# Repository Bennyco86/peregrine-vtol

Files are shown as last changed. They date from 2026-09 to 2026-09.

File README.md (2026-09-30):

# Peregrine: open-source VTOL FPV tail-sitter

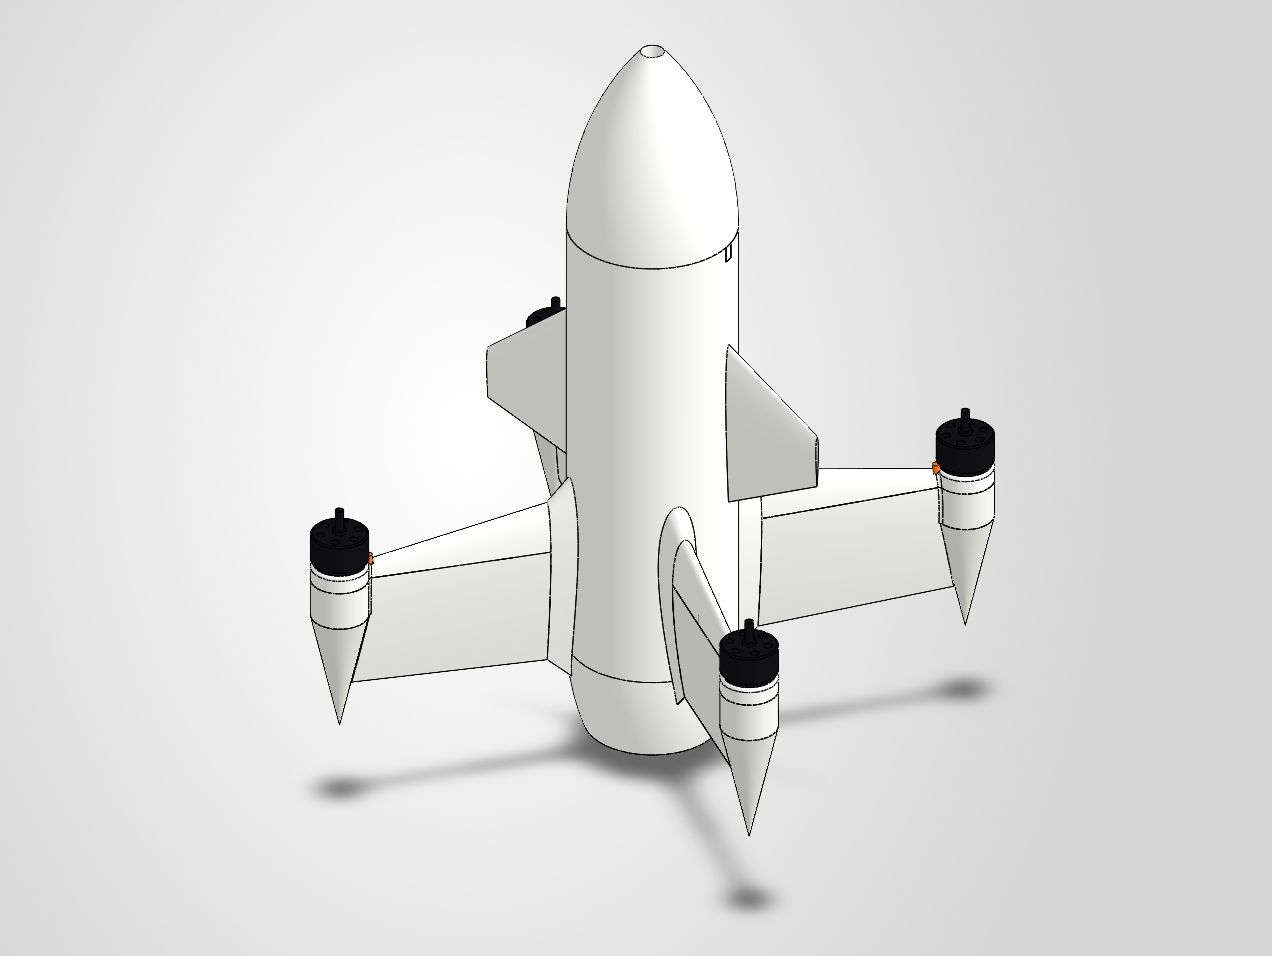
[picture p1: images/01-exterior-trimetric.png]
Peregrine, exterior


**Peregrine** (named after the peregrine falcon, the fastest animal on Earth) is a hobby **VTOL tail-sitter**. It stands on its four wing-tip spikes, takes off and hovers like a quadcopter, then pitches nose-forward and flies on its wings. It uses four motors and no control surfaces. **Design target: 200 km/h (56 m/s) in forward flight.**

I used **Claude Opus 5.5** and CAD to design it from a photo of the new Ukrainian interceptor drone, then gave it my own twist: it is built around **hobbyist components that are easy to find**. It is shared as an **open-source FPV project**.

> Fly it within your local aviation rules.

## What's in the repo

| Folder / file | Contents |
|---|---|
| [`cad/step/`](cad/step) | STEP files of every part designed here, plus the full assembly without vendor parts. **Print the `Rev 2` body parts.** The assembly STEP and the renders still show the original one-piece body. |
| [`BOM.md`](BOM.md) | Full bill of materials with purchase links, radio and goggle recommendations |
| [`docs/WIRING.md`](docs/WIRING.md) | Every cable, connector, pad and route |
| [`software/SETUP.md`](software/SETUP.md) | Flashing ArduPilot, calibration, radio, OSD, first flights |
| [`software/ardupilot/`](software/ardupilot) | ArduPlane parameter file for the Kakute H7 (QuadPlane tail-sitter, airspeed sensor, high-speed gain scaling) |
| [`images/`](images) | CAD renders (exterior, x-ray, wiring) and CFD (airflow simulation) results |

## Key numbers

| | |
|---|---|
| Layout | Quad tail-sitter, motors at 45° / 135° / 225° / 315°, 190 mm from the axis |
| Length | about 460 mm (tail to nose) |
| Body | Ø100 mm tube, ogive nose, 2 swept canards, 4 aerofoil wings (NACA 00xx) |
| Power | 4 × 2807 1300 KV, 7″ tri-blade high-pitch props (7×5 / 7×6), 6S 2200 mAh |
| Top speed target | 200 km/h (56 m/s), with an airspeed sensor and speed-based gain scaling |
| Structure | 3D-printed in ASA or PA-CF |
| Flight controller | Holybro Kakute H7 + Tekko32 F4 50A 4-in-1 |
| Firmware | ArduPilot **ArduPlane** (`Q_TAILSIT_ENABLE = 2`, copter-motor tail-sitter) |
| Video | HDZero Freestyle V2 + Micro V3 camera (digital, MSP OSD) |
| RC | ExpressLRS 2.4 GHz |
| GPS | Holybro Micro M10 in the nose |

## Build notes

- **Split wings.** Each wing is a top part (leading-edge beam + motor nacelle) and a bottom part (panel), split along the seam line. The motor leads lie in a groove on the split face before the halves are pinned and glued, so nothing has to be threaded through a closed wing.
- **Tabbed root.** The wings slide into slots in the body's aerofoil root fairings.
- **Three-piece fuselage (Rev 2), so it prints on 250 mm printers.** `Tail Cap Rev 2` (42 mm) + `Body Rev 2` (245 mm) + `Nose Cone Rev 2` (159 mm) + `Nose Tip Rev 2` (64 mm). The joints are flush twist-lock bayonets (3 lugs, about 18° twist, snap bump) set inside the wall thickness, so the bore stays clear for the tray. The tail cap is glued; the nose is left unglued as a service hatch, and a wide key lug means it only fits one way. Test-print one joint first: the fit is designed with 0.2 mm clearance.
- **Screw-off nose tip for the camera.** `Nose Tip Rev 2` screws onto a threaded collar on the nose bulkhead (2.5 mm pitch, printable without supports when printed tip-up). Unscrew it to drop the camera into its cradle, fit the two M2 pivot screws from the side, and reach the GPS screws through the bulkhead. The collar sits entirely inside the tip, so the outer shape is unchanged.
- **Optional stiffener channels.** The wing panels (Ø6.2 mm) and canards (Ø2.1 mm) have empty channels in the CAD. They are not required and nothing for them is in the BOM; fill them with carbon tube/rod only if a printed part turns out too flexible.
- **Wiring.** All wiring is modelled and colour-coded in the CAD: orange = motors, red = battery, yellow = VTX power/UART, black = video coax, blue = MIPI, cyan = GPS, green = receiver.

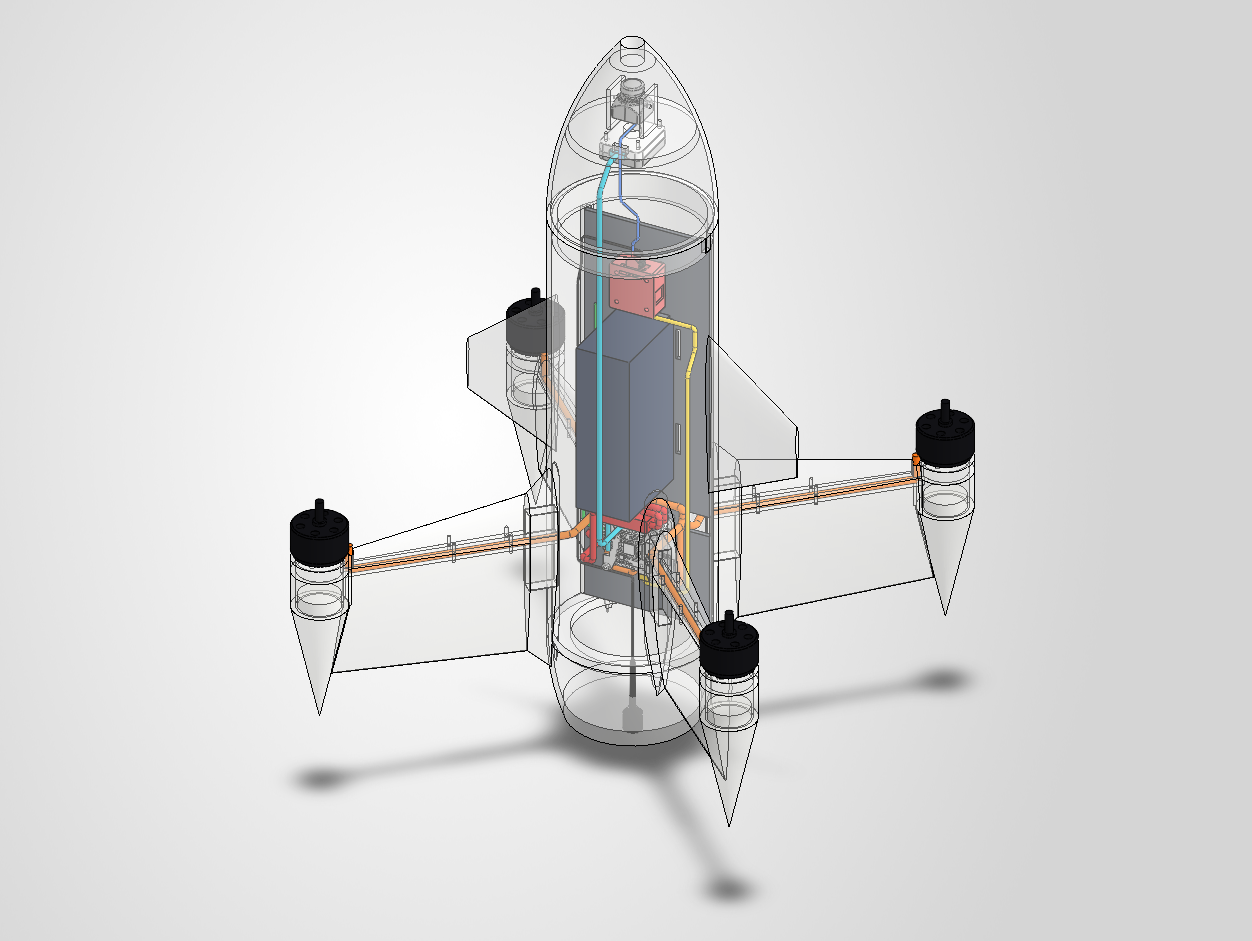
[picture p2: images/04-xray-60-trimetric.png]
x-ray

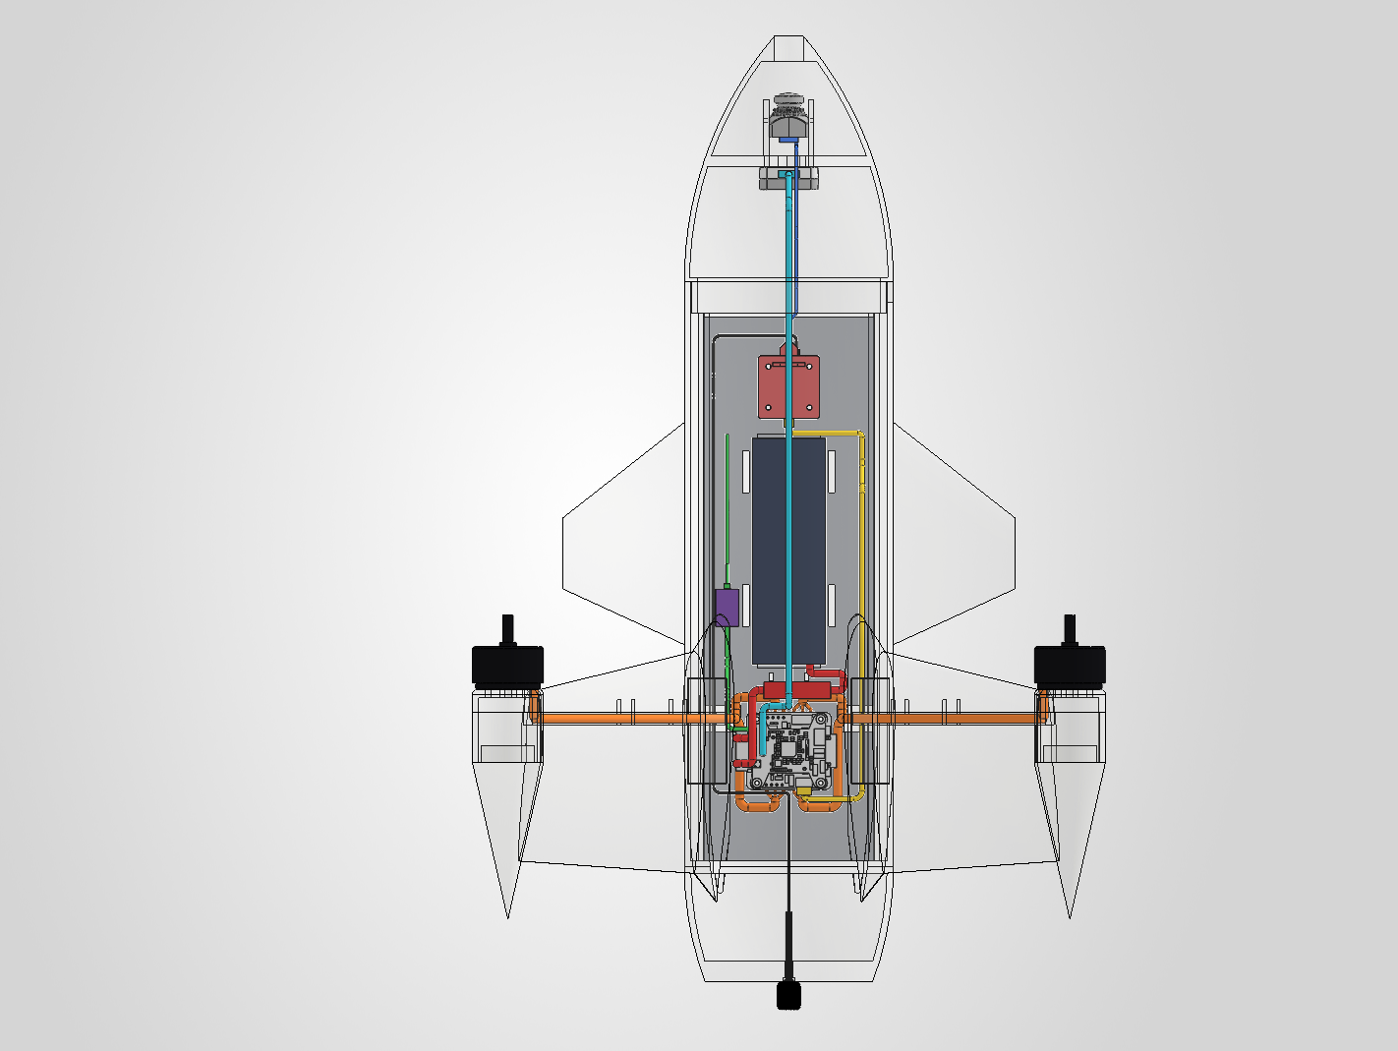
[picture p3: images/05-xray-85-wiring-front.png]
wiring, 85% transparent


| Front | Top (hover attitude) |
|---|---|
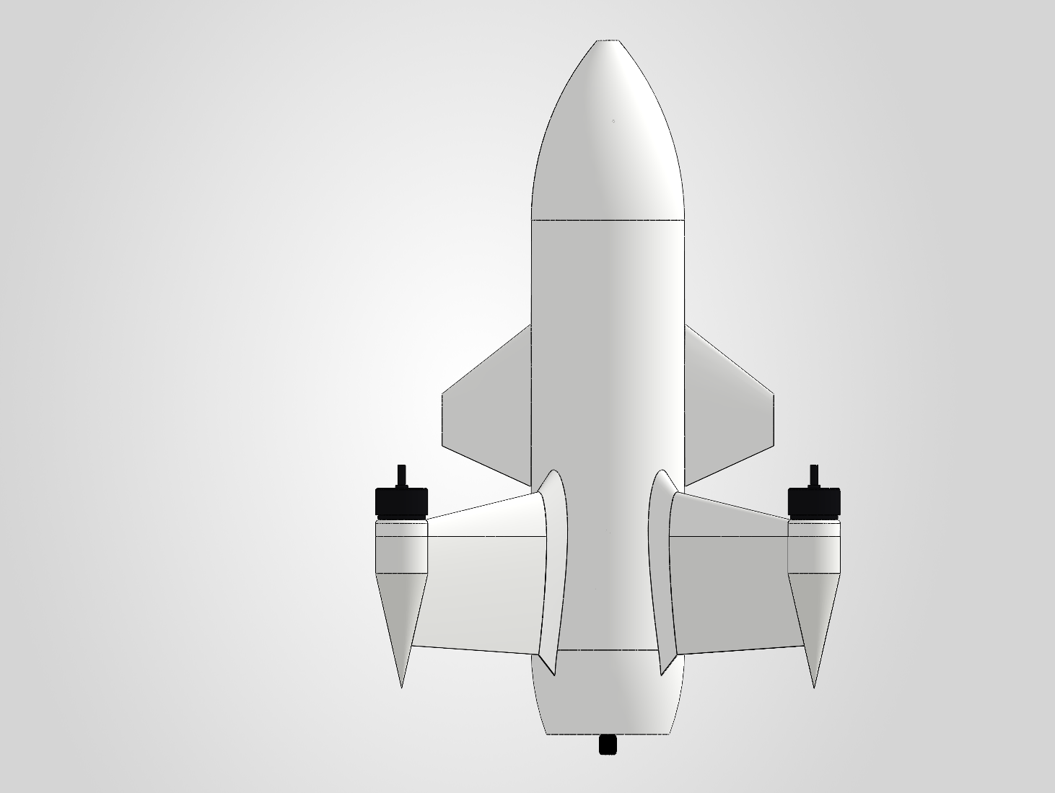
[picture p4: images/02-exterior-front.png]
front
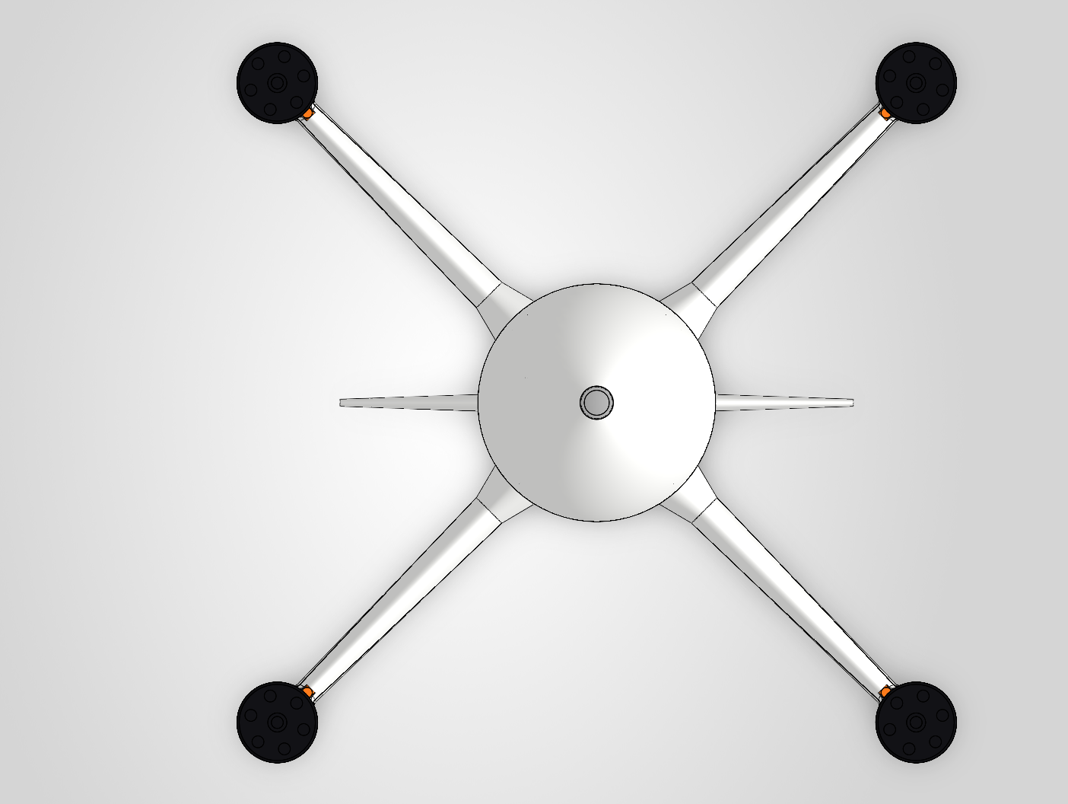
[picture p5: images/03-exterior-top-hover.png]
top
|  |  |

## CFD (airflow simulation)

External-flow CFD on the outer shape only (internal parts removed), air, nose-first forward flight.

### At the 200 km/h target (56 m/s)

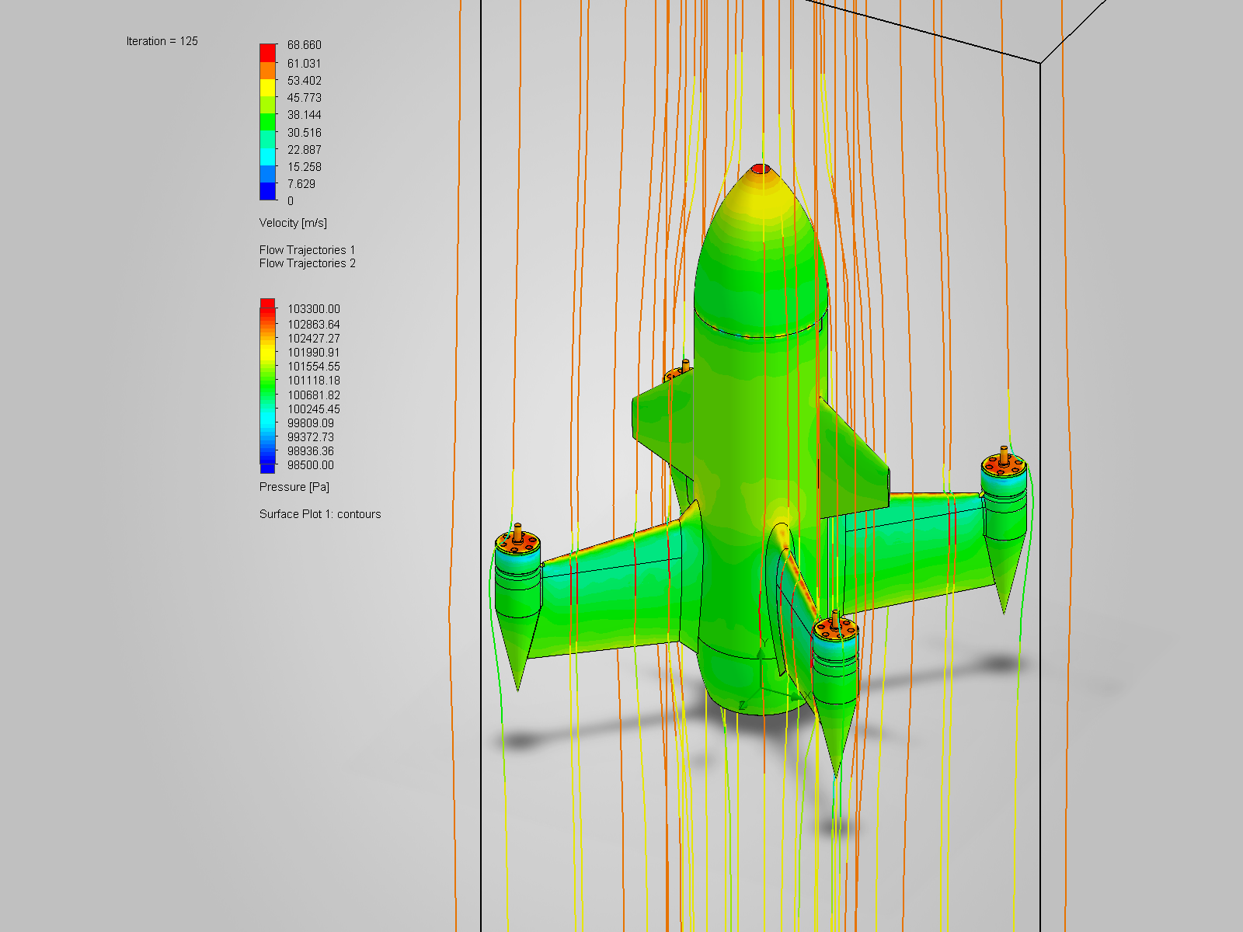
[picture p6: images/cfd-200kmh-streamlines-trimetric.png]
streamlines


| Result | Value |
|---|---|
| Drag at 200 km/h | **9.9 N** (about 1 kgf), converged |
| Drag area (C<sub>D</sub>·A) | about 0.0053 m² |
| Thrust power needed | about 550 W, roughly 40 A from a 6S pack with the props at 60 % efficiency |

Streamlines are coloured by velocity and the skin by pressure. Red marks stagnation at the nose tip, the wing leading edges and the motor bells; blue marks suction around the nacelles.

| Front | Isometric |
|---|---|
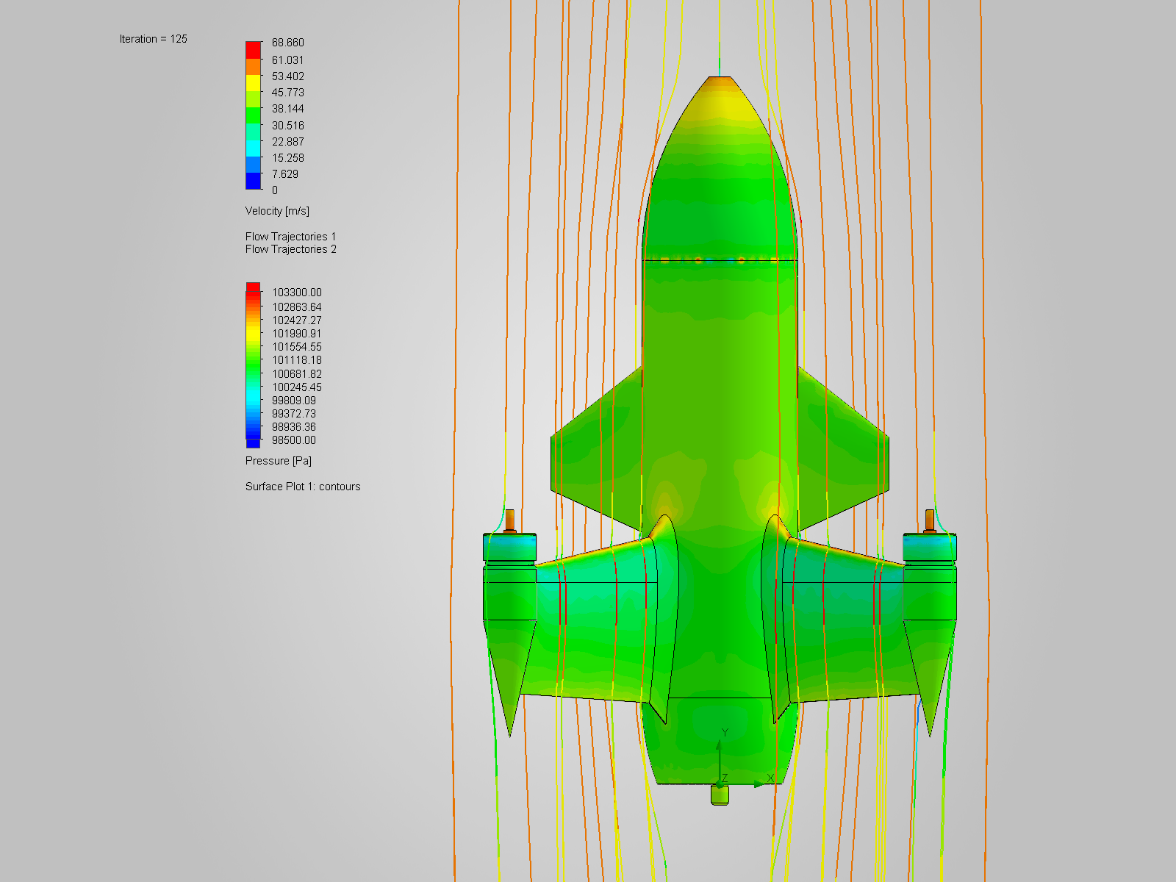
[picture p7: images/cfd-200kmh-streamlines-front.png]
front
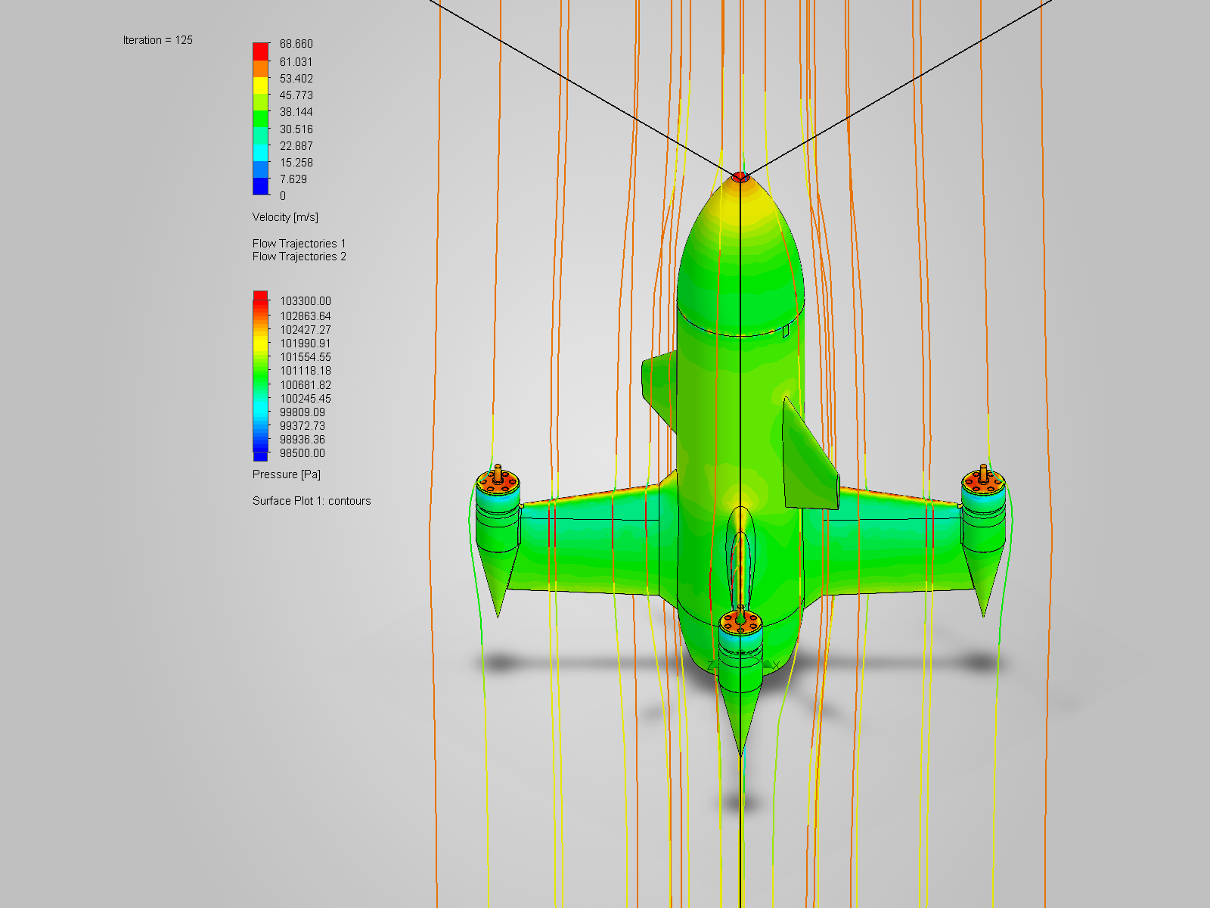
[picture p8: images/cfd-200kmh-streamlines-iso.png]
iso
|  |  |

### Shape study at 300 m/s (hypothetical)

> ⚠️ 300 m/s (Mach 0.87) is **not an achievable speed** for this airframe; it only shows where the shape builds shocks and wake. Colours *inside* the body tube are not meaningful (air enters through the camera opening in the model).

| Mach number | Velocity | Pressure |
|---|---|---|
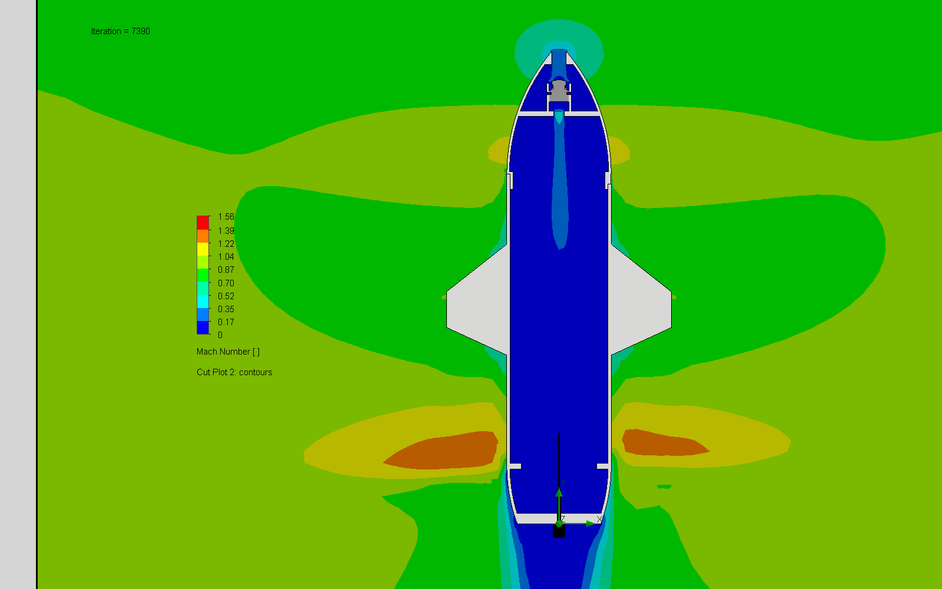
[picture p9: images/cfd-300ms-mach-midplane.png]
mach
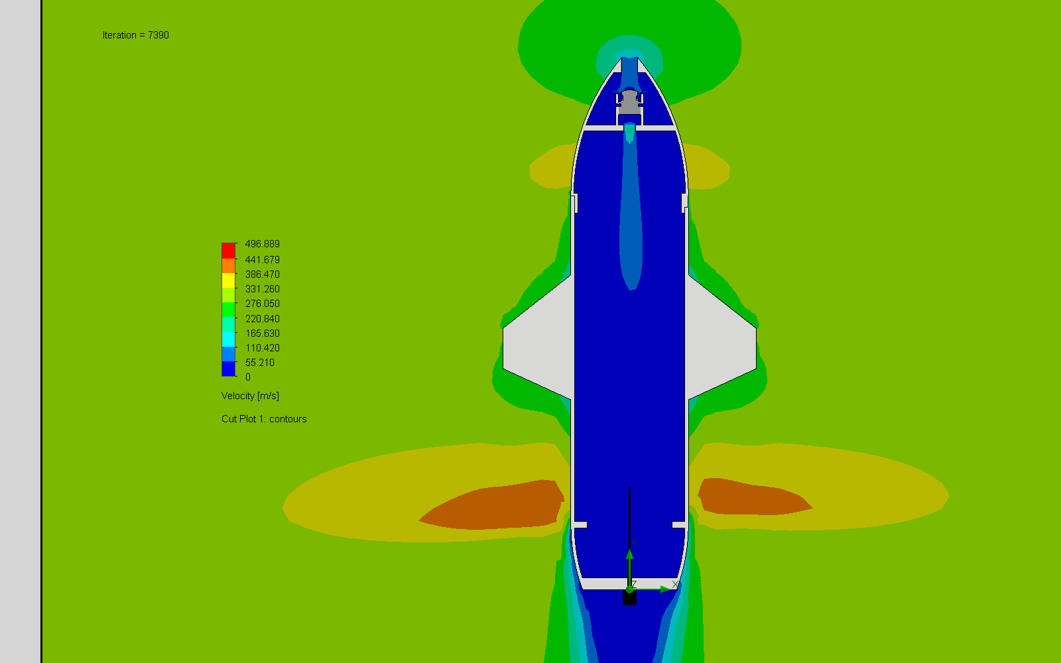
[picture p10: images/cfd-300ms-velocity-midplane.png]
velocity
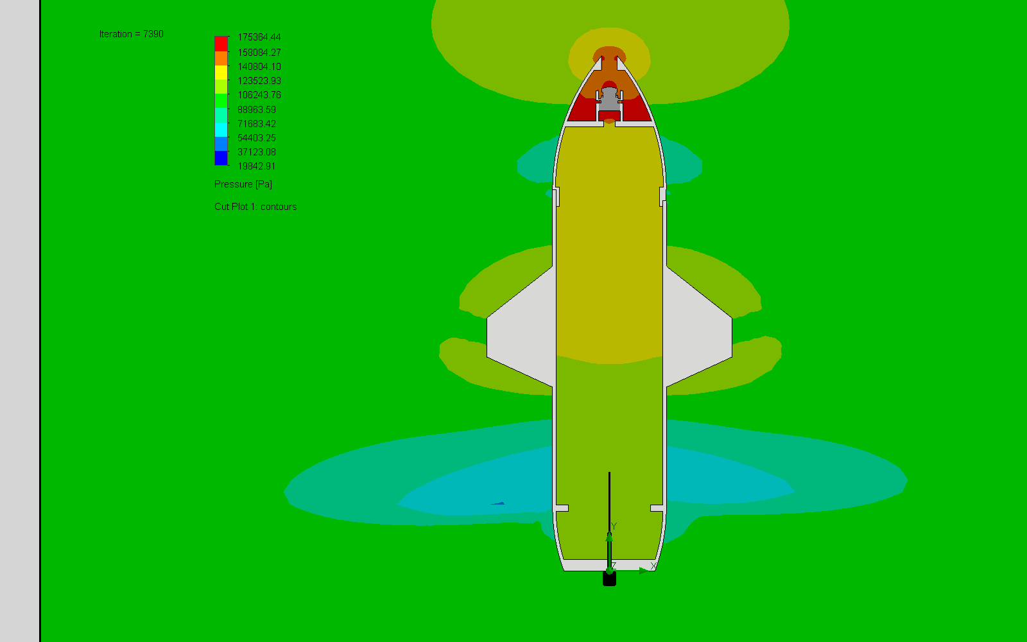
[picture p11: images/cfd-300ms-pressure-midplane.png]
pressure
|  |  |  |

## Vendor CAD (not included)

The assembly uses vendor models that are **not redistributed** here: HDZero CAD is CC BY-NC, and Holybro's terms are unknown. Download them yourself if you want the complete assembly:

- Holybro Kakute H7 / Tekko32 stack and Micro M10 GPS: [holybro.com](https://holybro.com) (product pages → downloads)
- HDZero Freestyle V2 VTX, antenna and Micro V2 camera (the model used in the CAD; buy the current Micro V3): [docs.hd-zero.com](https://docs.hd-zero.com/freestyle-v2)

The assembly STEP in `cad/step/` already leaves them out.

## Status

- ✅ CAD complete, interference-checked, all wiring connected
- ✅ ArduPilot parameters written (names checked against the ArduPilot docs, **not yet flight-tested**)
- ⏳ First build and hover test
- ✅ CFD at the 200 km/h target: drag 9.9 N
- ⏳ Mass properties + measured all-up weight (sets `Q_TAILSIT_DSKLD`)
- ⏳ Pitot tube (airspeed sensor) mount not modelled yet
- ⏳ Real build photos (current images are CAD renders)

## Licence

- Hardware (CAD, drawings, images, docs): **CC BY-SA 4.0**
- Software / configuration (parameter files): **GPL-3.0**, matching ArduPilot

See [`LICENSE`](LICENSE).

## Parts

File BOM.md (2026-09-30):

# Bill of Materials

Airframe and flight electronics only. There are no payload provisions.

Each part has a link to the official store or a known retailer (checked working on 30 Sep 2026) plus an AliExpress **search** link. Individual AliExpress listings expire too often to link directly.

**Prices** are estimates in **NZD**, taken from typical AliExpress and retailer listings in September 2026 at 1 USD ≈ 1.75 NZD. They exclude shipping; overseas orders to NZ also add 15 % GST at checkout. Treat them as a budget, not a quote.

## Cost summary

| Group | NZD (est.) |
|---|---|
| Flight electronics (#1–11a) | $957 |
| Wiring consumables (#12–17) | $39 |
| Filament (ASA, 1 kg spool) | $44 |
| Hardware (#24–30) | $19 |
| **Aircraft total** | **≈ $1,059** |
| Spare battery (strongly recommended) | $53 |
| Ground: radio + HDZero BoxPro goggles + charger | $840 |
| **Total to fly, with nothing already owned** | **≈ $1,952** |

If you already own a radio, goggles and a charger, the aircraft alone is about **NZ$1,060**.

Model column: **CAD** = vendor STEP used in the assembly (not redistributed, see the README) · **ENV** = envelope modelled from the datasheet · **OWN** = designed in this project

## Flight electronics

| # | Qty | Part | Role | Key spec / fit | Model | NZD (est.) | Buy |
|---|-----|---|---|---|---|-----|-----|
| 1 | 1 | Holybro **Kakute H7** (v1.3 or newer) + **Tekko32 F4 4-in-1 50A** stack | Flight controller + 4-in-1 ESC | 30.5 × 30.5 mm, 3–6S, 8-pin JST-SH FC↔ESC cable included | CAD | $236 | [Holybro (official)](https://holybro.com/products/kakute-h7-v1-stacks) · [AliExpress search](https://www.aliexpress.com/w/wholesale-kakute-h7-tekko32-stack.html) |
| 2 | 4 | **Hobbywing XRotor 2807 1300 KV** | Lift / thrust | Ø34 × 20.5 mm, **4 × M3 on a Ø19 mm circle** (the nacelle is drilled for this), M5 shaft. Many other 2807s use a 19 × 19 mm *square*, so check before you buy. | ENV | $140 (4 × $35) | [Hobbywing (official)](https://www.hobbywingdirect.com/products/xrotor-fpv-2807-motors) · [AliExpress search](https://www.aliexpress.com/w/wholesale-hobbywing-xrotor-2807-1300kv.html) |
| 3 | 2 + 2 (+ spares) | 7″ tri-blade **high-pitch** props, CW + CCW: **Gemfan Hurricane 7050** (7×5) | Thrust. Pitch sets top speed: 7×4 tops out around 120–130 km/h, 7×5 gives about 183 km/h of pitch speed and 7×6 about 220 km/h | M5 hub. Start with 7050s for hover tuning, then try 7×6 for the 200 km/h runs | — | $21 (2 packs) | [RaceDayQuads](https://www.racedayquads.com/products/gemfan-hurricane-7050-durable-tri-blade-7-prop-4-pack-choose-your-color) · [AliExpress search](https://www.aliexpress.com/w/wholesale-gemfan-7050-hurricane.html) |
| 4 | 1 | HDZero **Freestyle V2** VTX | Digital video TX | 20 × 20 mm, U.FL, MIPI, 6-pin to the FC. Buy the VTX-only option if the listing offers one. | CAD | $201 | [HDZero (official)](https://hdzero.us/products/hdzero-freestyle-v2-vtx) · [Pyrodrone](https://pyrodrone.com/products/hdzero-freestyle-v2-20x20-25-1000mw-hd-vtx-u-fl) · [AliExpress search](https://www.aliexpress.com/w/wholesale-hdzero-freestyle-v2.html) |
| 5 | 1 | 5.8 GHz U.FL antenna, RHCP (Foxeer Lollipop 4 Plus, U.FL) | Video antenna | Exits the tail on the body axis | CAD | $18 (2-pack) | [Foxeer (official)](https://www.foxeer.com/foxeer-lollipop-4-plus-high-quality-5-8g-2-6dbi-fpv-omni-lds-antenna-g-374) · [AliExpress search](https://www.aliexpress.com/w/wholesale-foxeer-lollipop-4-plus-ufl.html) |
| 6 | 1 | HDZero **Micro V3** camera (replaces the discontinued Micro V2) | FPV camera | Same 19 × 19 mm micro mount as the V2 in the CAD; the V3 body is 24 mm deep, so check the fit in the nose cradle. MIPI cable not included. | CAD | $100 | [HDZero (official)](https://hdzero.us/products/hdzero-micro-v3-camera) · [AliExpress search](https://www.aliexpress.com/w/wholesale-hdzero-micro-v3-camera.html) |
| 7 | 1 | HDZero MIPI cable, **250 mm** | Camera → VTX | Modelled route is about 152 mm | OWN (route) | $30 | [HDZero (official)](https://hdzero.us/products/hdzero-mipi-cable-250mm) · [Pyrodrone](https://pyrodrone.com/products/hdzero-mipi-cable-250mm) · [AliExpress search](https://www.aliexpress.com/w/wholesale-hdzero-mipi-cable-250mm.html) |
| 8 | 1 | U.FL / IPEX 1.13 mm extension, **300 mm** | VTX → tail antenna | Modelled route is about 250 mm | OWN (route) | $5 | [AliExpress search](https://www.aliexpress.com/w/wholesale-ipex-ufl-1.13-extension-cable-30cm.html) |
| 9 | 1 | Holybro **Micro M10 GPS** | Position / RTL | 25 × 25 mm, JST-GH 6-pin (UART + I²C compass), mounted in the nose | CAD | $49 | [Holybro (official)](https://holybro.com/products/micro-m10-gps) · [AliExpress search](https://www.aliexpress.com/w/wholesale-holybro-micro-m10-gps.html) |
| 10 | 1 | ExpressLRS 2.4 GHz receiver: **RadioMaster RP1 V2** | RC link | about 11 × 18 × 3 mm, CRSF on UART6 | ENV | $30 | [RadioMaster (official)](https://radiomasterrc.com/products/rp1-expresslrs-2-4ghz-nano-receiver) · [AliExpress search](https://www.aliexpress.com/w/wholesale-radiomaster-rp1-v2.html) |
| 11 | 1 | 6S 2200 mAh LiPo, XT60: **CNHL G+Plus 70C** | Power. Expect only 2–3 min at full speed | 109 × 35 × 51 mm, about 349 g. The tray pocket is 111 mm long. | ENV | $53 | [CNHL (official)](https://chinahobbyline.com/products/cnhl-gplus-series-2200mah-22-2v-6s-70c-lipo-battery-with-xt60-plug) · [AliExpress search](https://www.aliexpress.com/w/wholesale-cnhl-2200mah-6s-70c.html) |
| 11a | 1 | **Matek ASPD-4525** digital airspeed sensor (MS4525DO, I²C, comes with pitot + tubing) | Real airspeed for gain scaling, speed limits and the OSD. Strongly recommended for high-speed flight | Pitot must sit in clean air ahead of the canards (see WIRING.md) | — | $74 | [Matek (official)](https://www.mateksys.com/?portfolio=aspd-4525) · [AliExpress search](https://www.aliexpress.com/w/wholesale-matek-aspd-4525.html) |
| | | | | | | **$957** | |

## Wiring consumables

| # | Qty | Part | Used for | NZD (est.) | Buy |
|---|-----|---|---|-----|-----|
| 12 | 1 | XT60 female pigtail, 12 AWG, about 100 mm | Battery → ESC pads | $5 | [AliExpress search](https://www.aliexpress.com/w/wholesale-xt60-pigtail-12awg.html) |
| 13 | 1 | Low-ESR capacitor 35 V 470–1000 µF | Across the ESC battery pads | incl. | Supplied with the stack |
| 14 | 1 m | 18 AWG silicone wire (3 colours) | Motor lead extensions, about 180 mm × 3 per motor | $18 | [AliExpress search](https://www.aliexpress.com/w/wholesale-18awg-silicone-wire.html) (choose 18 AWG) |
| 15 | 1 | Heat-shrink assortment (+ 3 mm braided sleeve) | Motor bundles in the wing grooves | $9 | [AliExpress search](https://www.aliexpress.com/w/wholesale-heat-shrink-tube-kit.html) |
| 16 | — | JST-SH / JST-GH leads | FC ↔ ESC, FC ↔ VTX, FC ↔ GPS | incl. | Supplied with the stack, VTX and GPS |
| 17 | 30 cm | 28 AWG silicone wire (4 colours) | FC ↔ receiver | $7 | [AliExpress search](https://www.aliexpress.com/w/wholesale-28awg-silicone-wire.html) |
| | | | | **$39** | |

## Printed parts

For 200 km/h, print the wings and canards in **ASA or carbon-fibre nylon (PA-CF)** with 4+ walls. PETG flexes and LW-PLA is too soft at this speed. STEP files are in [`cad/step`](cad/step).

| # | Qty | File | Notes |
|---|-----|---|---|
| 18 | 1 | `Body Rev 2` | Ø100 mm tube, 4 aerofoil root fairings with tab slots, 2 swept canards, tray rails. **245 mm tall, so it fits 250 mm printers.** Bayonet sockets at both ends. |
| 19 | 1 | `Nose Cone Rev 2` | Ogive nose with the bulkhead, camera cradle and GPS mount, extended down to take the forward tube. **Twist-lock bayonet with a snap onto the body: do not glue**, it is the service hatch. A wide key lug means it fits only one way. It has a threaded collar (2.5 mm pitch) around the camera. |
| 19b | 1 | `Nose Tip Rev 2` | The front of the nose around the camera, with the lens window. **Screws onto the threaded collar** (about 2.5 turns). Unscrew it to fit the camera and reach the pivot and GPS screws. |
| 19a | 1 | `Tail Cap Rev 2` | Tapered tail end with the antenna hole (42 mm tall). Twist-lock bayonet with a snap, **glued** once the wiring is in (glue groove on the ring). |
| 20 | 4 | `Wing - Top Part` | Leading-edge beam + motor nacelle |
| 21 | 4 | `Wing - Bottom Part` | Wing panel. The 6 × 6 mm motor-lead groove is on the split face |
| 22 | 4 | `Spike` | Landing leg / nacelle tail cone (TPU is fine) |
| 23 | 1 | `Avionics Tray` | Stack and VTX standoffs, battery pocket between two ribs, slots for the lower motor-lead bundles |
| — | — | `Arm` | Unsplit master of the wing, for editing only (not printed) |

**Filament:** about 450 g in total. Budget one 1 kg spool of ASA (about NZ$44), or about NZ$80 if you print the wings and canards in PA-CF.

## Hardware

| # | Qty | Part | Used for | NZD (est.) | Buy |
|---|-----|---|---|-----|-----|
| 24 | 16 | M3 × 8 socket screws | Motors → nacelles | $12 (kit) | [AliExpress search](https://www.aliexpress.com/w/wholesale-m2-m3-hex-socket-screw-kit.html) |
| 25 | 4 | M3 × 20 screws + nylon nuts (or the stack's own bolts) | Stack → tray | in kit | same kit |
| 26 | 4 | M2 × 5 screws | VTX → tray | in kit | same kit |
| 27 | 4 | M2 × 5 screws | GPS → nose bulkhead | in kit | same kit |
| 28 | 2 | M2 × 6 screws | Camera tilt pivot | in kit | same kit |
| 29 | 16 | 1.75 mm filament pins, 12 mm long | Wing top ↔ bottom alignment (plus CA or epoxy) | incl. | Offcuts of your filament |
| 30 | 1 | Battery strap, 20 mm | Battery retention | $7 | [AliExpress search](https://www.aliexpress.com/w/wholesale-lipo-battery-strap-20mm.html) |
| | | | | **$19** | |

## Ground equipment (not on the aircraft)

| Item | Recommendation | Why | NZD (est.) | Buy |
|---|---|-----|-----|-----|
| Radio | **RadioMaster Pocket (ELRS)** | Cheap, compact, EdgeTX, internal ELRS that binds to the RP1 | $123 | [RadioMaster (official)](https://radiomasterrc.com/products/pocket-radio-controller-m2) · [AliExpress search](https://www.aliexpress.com/w/wholesale-radiomaster-pocket-elrs.html) |
| Goggles (**best value**) | **HDZero BoxPro** (US$349.99) | The cheapest goggles that receive HDZero natively. 100 Hz 1800-nit LCD, built-in DVR, analog receiver and HDMI in. Less than half the price of Goggle 2. BoxPro+ (US$399.99) only upgrades the optics. | $612 | [HDZero (official)](https://hdzero.us/products/hdzero-boxpro-boxpro) · [AliExpress search](https://www.aliexpress.com/w/wholesale-hdzero-boxpro.html) |
| Goggles (premium, not needed) | HDZero Goggle 2 (US$749.99) | OLED and slightly lower latency; about double the BoxPro price for a small gain | $1,312 | [HDZero (official)](https://hdzero.us/products/hdzero-goggle-2) |
| Charger | Any 6S-capable AC/DC balance charger (e.g. ToolkitRC / ISDT class) | Charges the 6S packs | about $105 | — |
| Ground station | Mission Planner or QGroundControl on a PC | Setup, tuning, logs | free | — |

**Do you need FPV?** The hover modes (`QSTABILIZE`, `QHOVER`, `QLOITER`) can be flown line-of-sight with just the radio. Forward (wing-borne) flight covers ground fast and is flown through the camera, so plan on goggles plus a spotter where your local rules require one.

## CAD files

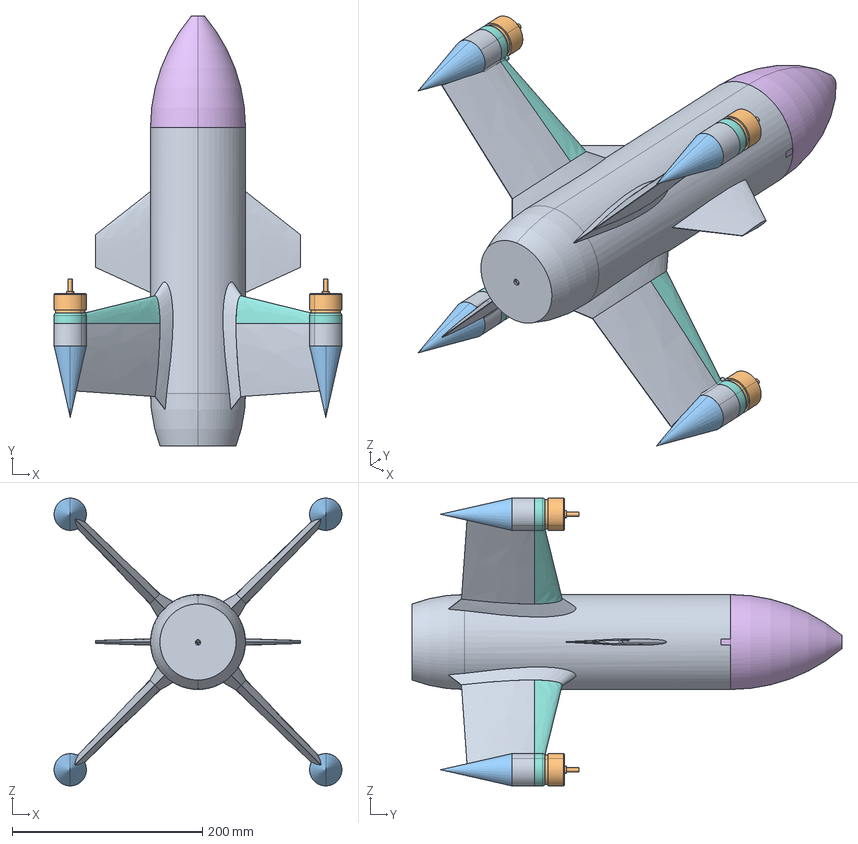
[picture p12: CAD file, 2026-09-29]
cad/step/Rocket VTOL Drone - assembly (no vendor parts).step
302.7 x 452.2 x 302.7 mm
Motor x 4
Spike x 4
Avionics Tray
Receiver ELRS
Nose Cone
Battery CNHL 6S 2200mAh
Harness - Motor Leads
Harness - Camera MIPI Cable
Harness - VTX Antenna Coax
Harness - GPS Cable
Harness - Battery Lead XT60
Harness - RX Cable
Wing - Top Part x 4
Wing - Bottom Part x 4
Harness - VTX Power UART

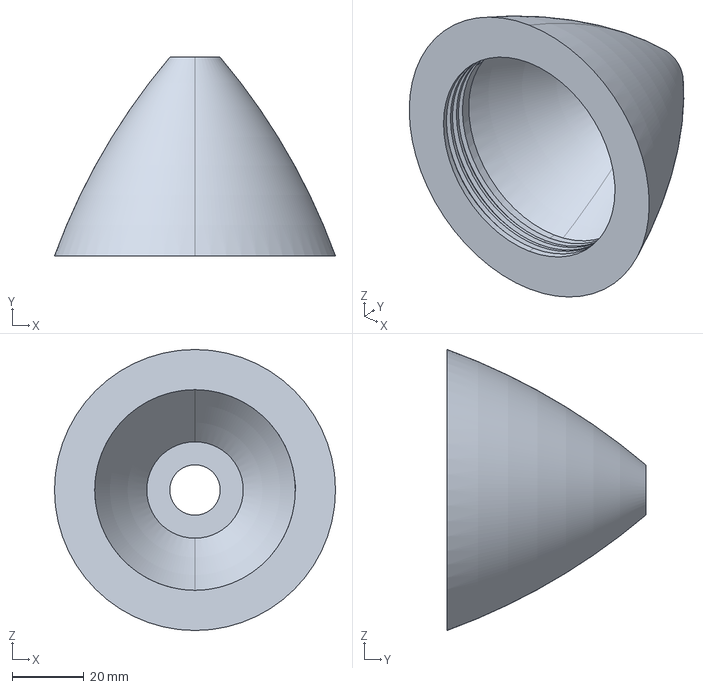
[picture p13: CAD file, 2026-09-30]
cad/step/Nose Tip Rev 2.step
78.1 x 55.2 x 78.1 mm

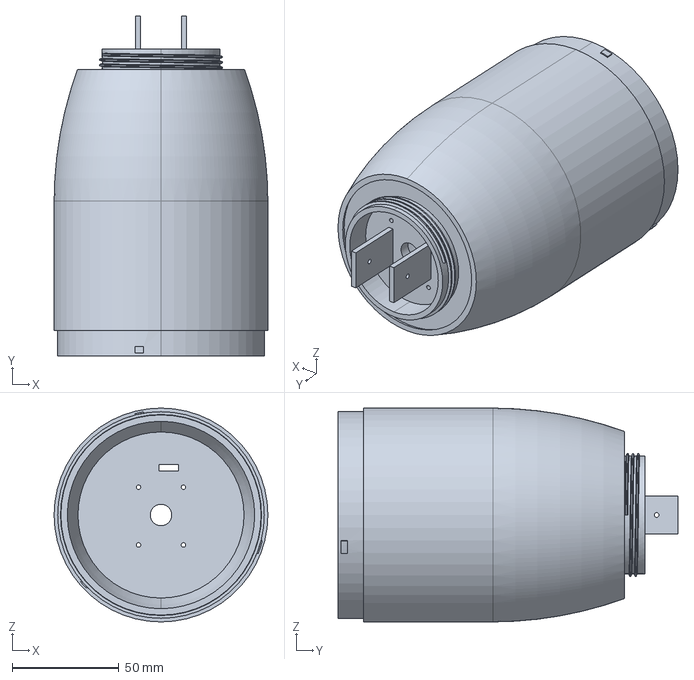
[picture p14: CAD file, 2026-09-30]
cad/step/Nose Cone Rev 2.step
100.0 x 159.0 x 100.0 mm

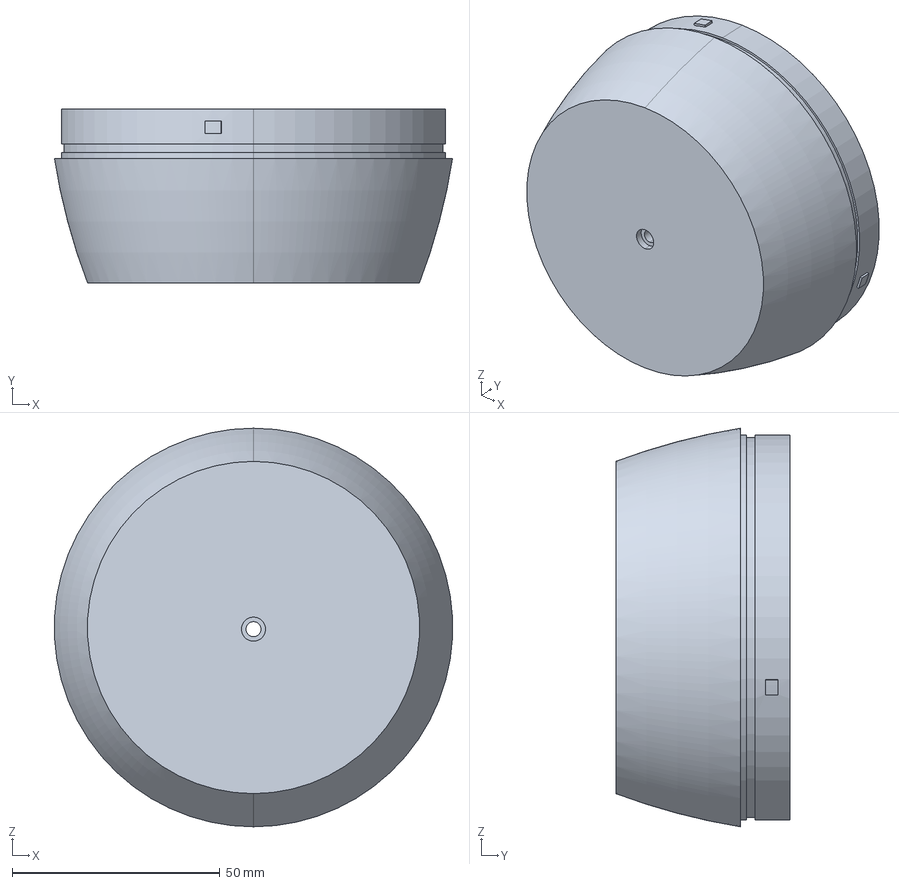
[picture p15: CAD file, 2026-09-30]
cad/step/Tail Cap Rev 2.step
95.8 x 42.0 x 96.0 mm

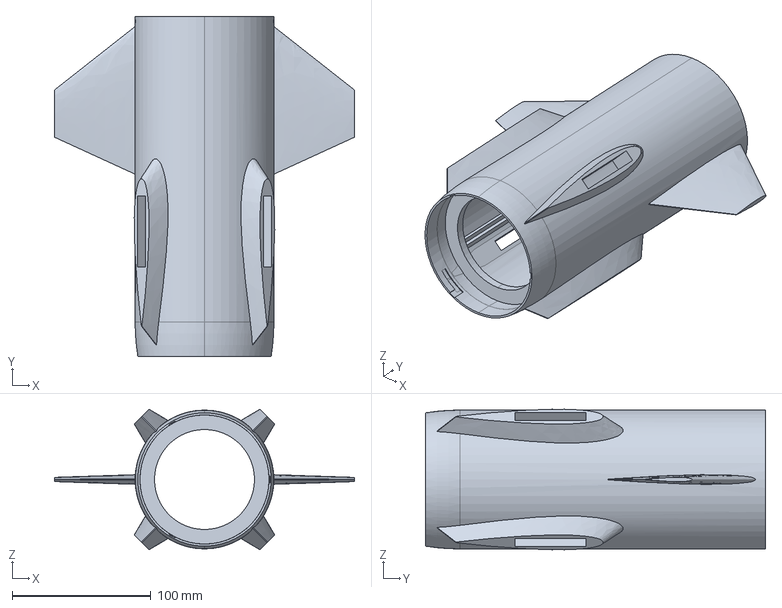
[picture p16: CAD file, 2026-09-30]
cad/step/Body Rev 2.step
216.0 x 245.0 x 101.2 mm

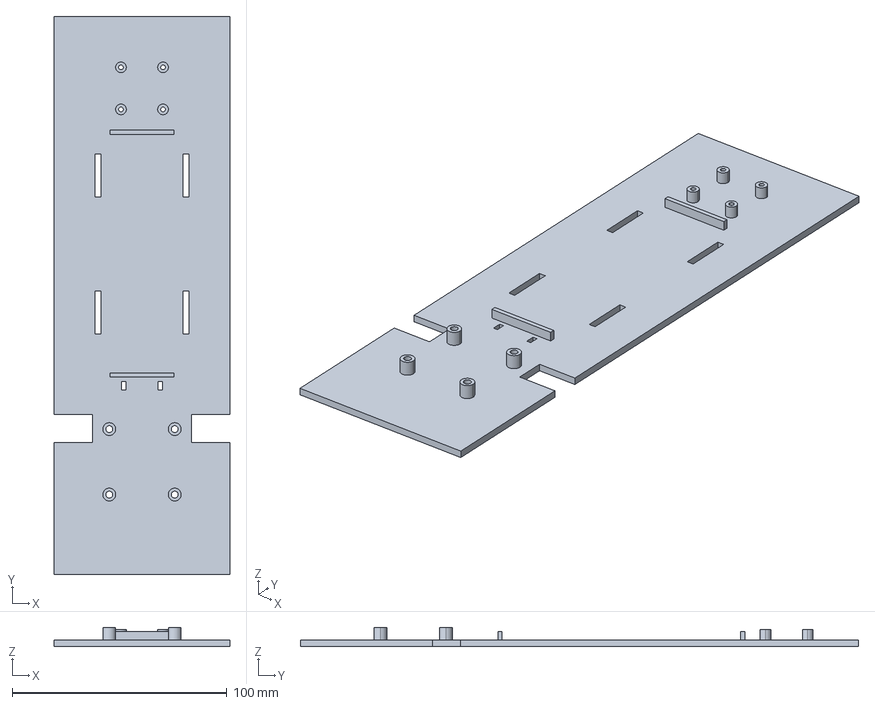
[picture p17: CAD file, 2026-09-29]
cad/step/Avionics Tray.step
82.0 x 260.0 x 9.00 mm

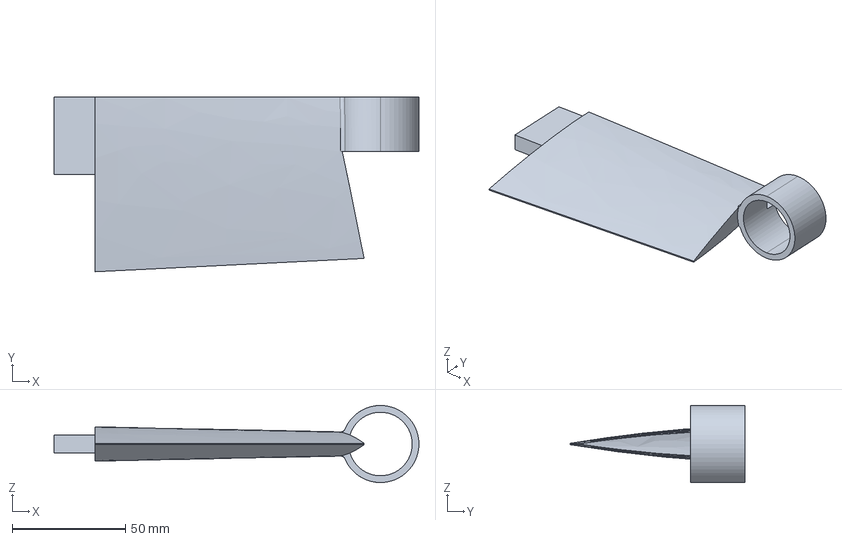
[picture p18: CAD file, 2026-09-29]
cad/step/Wing - Bottom Part.step
161.0 x 77.0 x 34.0 mm

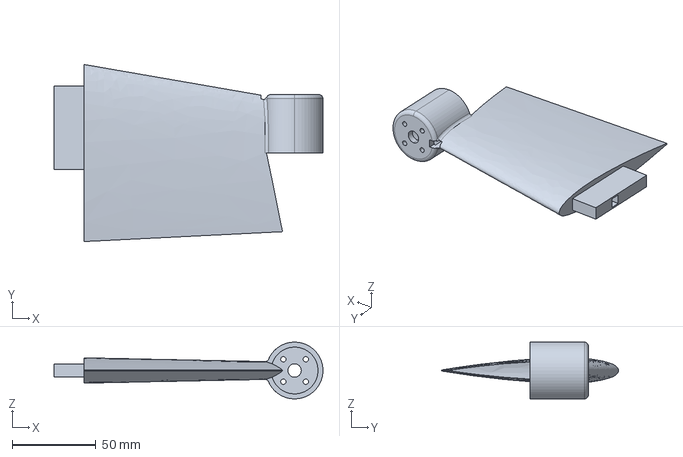
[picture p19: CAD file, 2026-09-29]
cad/step/Arm.step
161.0 x 106.0 x 34.0 mm

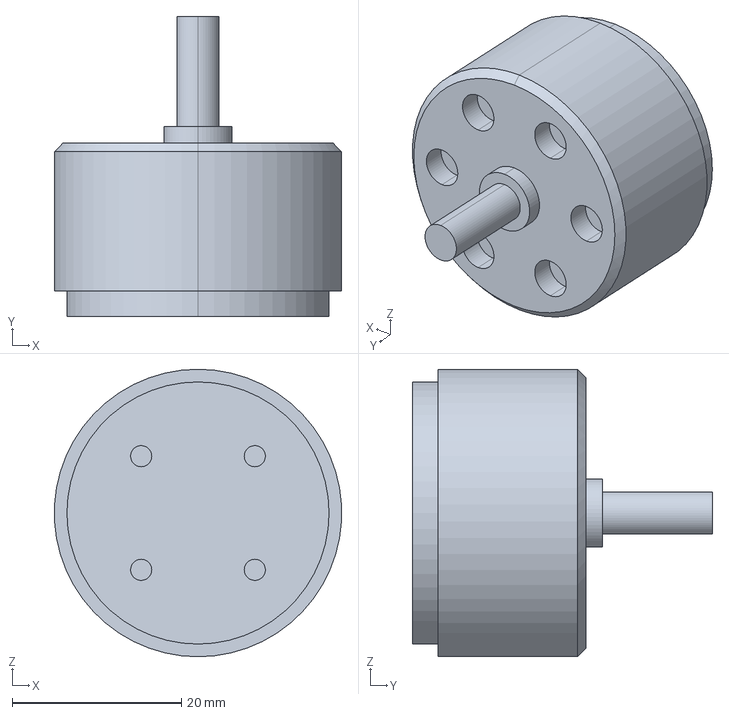
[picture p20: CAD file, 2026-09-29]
cad/step/Motor.step
33.9 x 35.5 x 34.0 mm

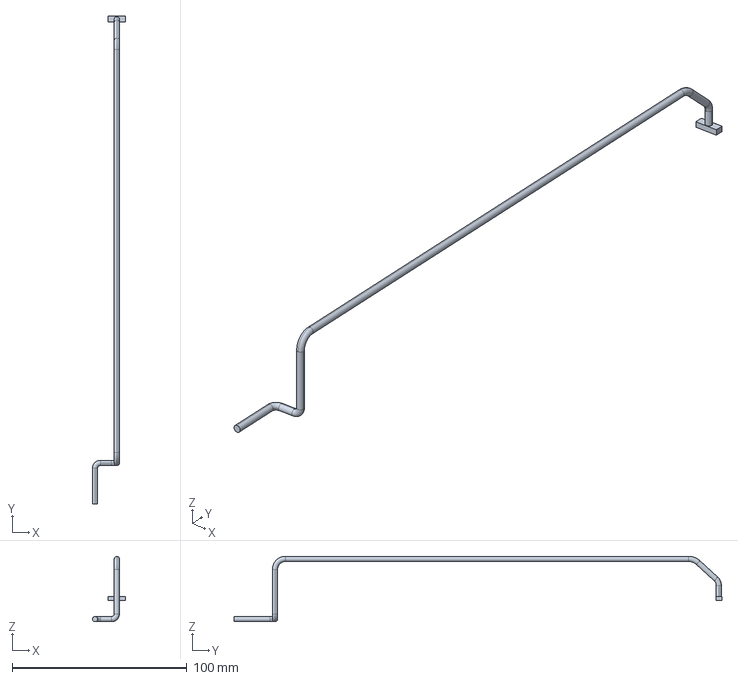
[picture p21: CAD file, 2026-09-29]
cad/step/Harness - GPS Cable.step
19.0 x 279.5 x 37.5 mm

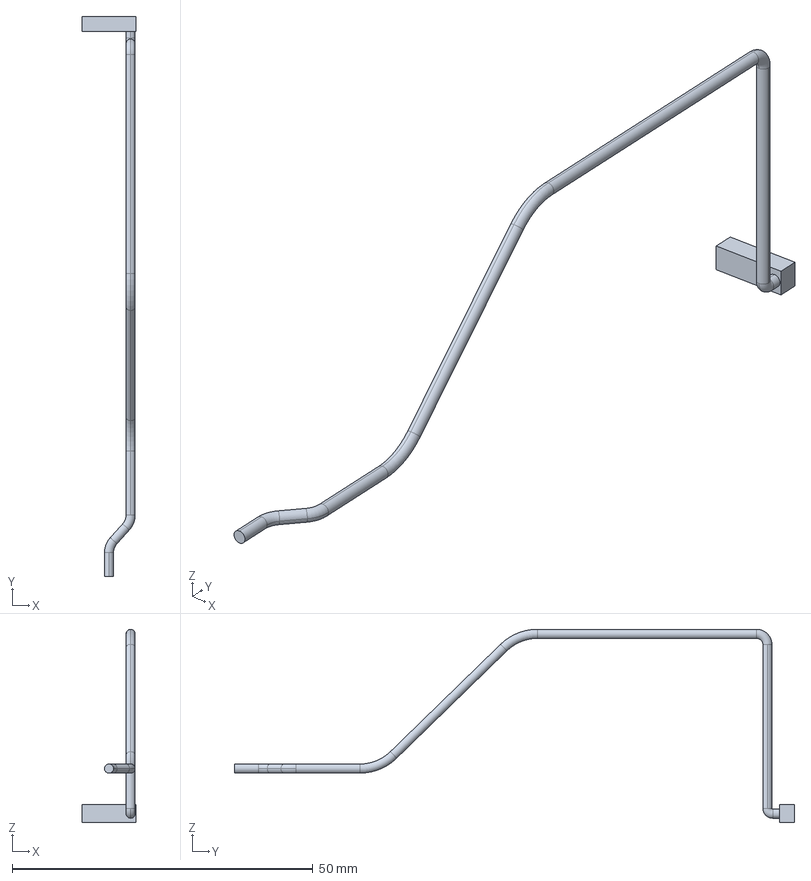
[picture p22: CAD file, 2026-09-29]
cad/step/Harness - Camera MIPI Cable.step
9.00 x 93.1 x 32.2 mm

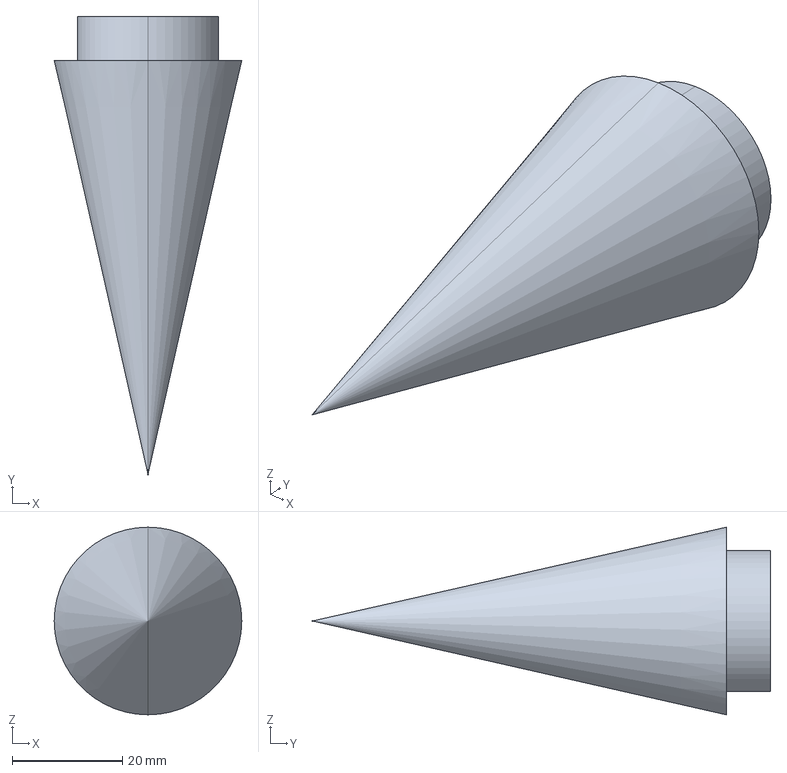
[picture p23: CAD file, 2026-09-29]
cad/step/Spike.step
34.0 x 83.0 x 34.0 mm

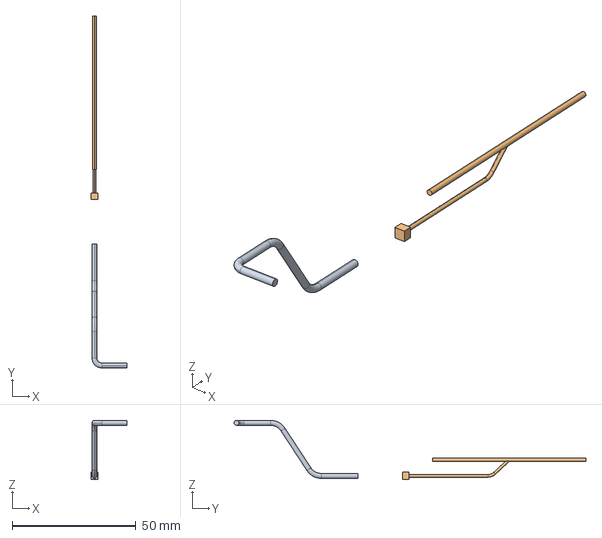
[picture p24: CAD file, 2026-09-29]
cad/step/Harness - RX Cable.step
14.7 x 142.0 x 23.9 mm

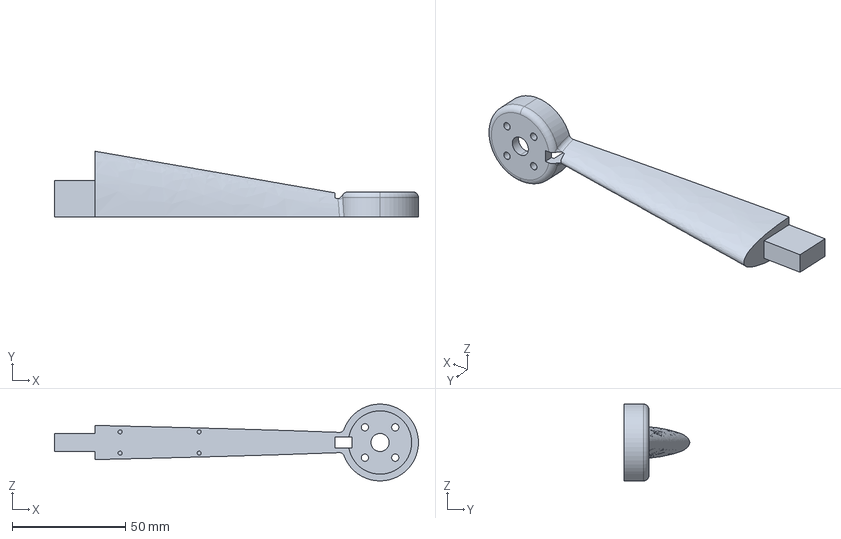
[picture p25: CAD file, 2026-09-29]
cad/step/Wing - Top Part.step
161.0 x 29.0 x 34.0 mm

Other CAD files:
cad/step/Battery CNHL 6S 2200mAh.step
cad/step/Harness - VTX Antenna Coax.step
cad/step/Harness - Motor Leads.step
cad/step/Receiver ELRS.step
cad/step/Harness - Battery Lead XT60.step
cad/step/Harness - VTX Power UART.step

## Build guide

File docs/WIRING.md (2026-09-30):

# Wiring

Every cable in the CAD assembly is modelled end to end, from a real pad or connector to a real pad or connector. The harness parts are colour-coded in the model and in the renders:

| # | Link | Colour in CAD | From → To | Connector / pads | Route |
|---|---|---|---|---|---|
| 1 | FC ↔ ESC | (inside the stack) | Kakute H7 ↔ Tekko32 4-in-1 | 8-pin JST-SH, supplied with the stack | Straight down between the stacked boards (30.5 mm pattern). It carries motor signals, current sense and ESC telemetry (UART7 → `SERIAL7_PROTOCOL = 16`). |
| 2 | Motor leads ×4 | Orange | ESC motor pads → motors | 3 × 18 AWG per motor, soldered | The front and rear pad rows each feed two motors. The leads bundle beside the stack, rise into the root fairing, run through the **6 × 6 mm groove on the split face of `Wing - Bottom Part`**, then up the nacelle slot to the motor base. |
| 3 | Battery lead | Red | ESC battery pads → XT60 | 12 AWG pigtail + XT60 pair | Short riser from the pads to an XT60 lying across the tray. The battery's own XT60 plugs in from the rear. Solder the low-ESR capacitor across the battery pads. |
| 4 | VTX power + UART | Yellow | FC HD/VTX port → HDZero VTX | 6-pin JST-SH both ends (9 V, GND, UART1 TX/RX) | Runs along the tray to the VTX at the front of the bay. `SERIAL1_PROTOCOL = 42` (MSP DisplayPort OSD). |
| 5 | Video antenna coax | Black | VTX U.FL → tail antenna | U.FL, 1.13 mm coax (300 mm extension) | Runs aft under the tray to the tail and leaves on the body axis through the Ø3.6 mm hole (Ø5.8 × 2 mm counterbore for the ferrule). |
| 6 | Camera MIPI | Blue | VTX MIPI port → HDZero Micro V3 (V2 in the CAD, same mount) | HDZero MIPI ribbon, 250 mm | About 152 mm of route plus slack, forward into the nose cradle. Keep it away from the motor leads. |
| 7 | GPS | Cyan | Micro M10 (nose) → FC pads | JST-GH 6-pin at the GPS, soldered at the FC: 5 V, GND, TX3, RX3, SCL, SDA | The GPS sits in the nose cone above the camera, screwed through the bulkhead. The cable runs aft along the canopy side. `SERIAL3_PROTOCOL = 5`, `GPS_TYPE = 2`. |
| 8 | ELRS receiver | Green | RX (beside the battery, −X side) → FC UART6 pads | 4 × 28 AWG: 5 V, GND, RX-TX → **R6**, RX-RX → **T6** | Short run forward to the stack. The 2.4 GHz T-antenna lies along the body axis on the bottom skin, away from the video antenna. `SERIAL6_PROTOCOL = 23`, `RSSI_TYPE = 3`. |
| 9 | Airspeed sensor | (not in CAD yet) | Matek ASPD-4525 → FC I²C pads | JST-GH 4-pin: 5 V, GND, SCL, SDA (shared with the GPS compass bus) | Mount the board inside the nose bay. Run the silicone tubes to a pitot tube that pokes forward through a canard leading edge or the nose-to-body joint, **out of the prop wash and at least 20 mm ahead of the local surface**. `ARSPD_TYPE = 1`. |

## Notes

- **Wing split.** Each wing is printed as a top part (leading-edge beam + motor mount) and a bottom part (panel). Lay the motor leads in the bottom part's groove, then close the wing on 4 filament pins (Ø1.75 mm) with CA or epoxy. The leads never have to be pulled through a closed tube.
- **Motor direction.** Swap any two motor wires, or better, reverse the motor in BLHeli_32 / AM32. The motor order follows ArduPilot Quad X in the hover attitude (see [`software/SETUP.md`](../software/SETUP.md)).
- **RF separation.** The 5.8 GHz video antenna exits the tail and the 2.4 GHz RX antenna lies on the bottom skin, so neither antenna shadows the other in hover (nose up) or in forward flight.
- **Checks before the first power-up.** Beep out the battery pads for shorts, check the XT60 polarity, and power the stack from a smoke stopper the first time.

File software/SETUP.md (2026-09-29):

# Software setup

Every piece of software here is open source or free, and none of it is written for this airframe. The only project-specific file is the ArduPilot parameter file.

| Layer | Software | Licence | What it does here |
|---|---|---|---|
| Flight controller firmware | [ArduPilot **ArduPlane**](https://ardupilot.org/plane/), target `KakuteH7` | GPLv3 | Motor-only tail-sitter: hovers like a quad, transitions nose-forward like a plane |
| Ground control | [Mission Planner](https://ardupilot.org/planner/) or [QGroundControl](https://qgroundcontrol.com/) | GPLv3 / Apache-2.0 | Flashing, parameters, calibration, motor test, logs |
| ESC firmware | BLHeli_32 or AM32 (factory on the Tekko32) | AM32 is GPLv3 | DShot600 + telemetry, no changes needed |
| Radio link | [ExpressLRS](https://www.expresslrs.org/) + [EdgeTX](https://edgetx.org/) on the transmitter | GPLv3 | CRSF RC link and telemetry |
| Video | HDZero firmware (VTX + goggles) | vendor | Digital video, MSP DisplayPort OSD |

## 1. Flash the flight controller

1. Hold the Kakute H7 boot button, plug in USB-C, and flash **ArduPlane stable** for board `KakuteH7`. Use Mission Planner (*Install Firmware*) or the ArduPilot firmware server.
2. Connect, set `Q_ENABLE = 1`, write, then **reboot**.
3. Load `ardupilot/peregrine-kakuteh7.param` (*Config → Full Parameter List → Load from file*), write, then reboot again.

## 2. Orientation and calibration: do these in the FIXED-WING attitude

ArduPilot treats forward flight as the "normal" attitude for a tail-sitter. Lay the aircraft nose-forward with the canards level for all of these:

- `AHRS_ORIENTATION`: the stack lies in the body's XY plane with the component side facing the canopy (+Z). If the FC arrow points at the nose, leave it at `0`. Otherwise pick the matching yaw rotation.
- Accelerometer calibration (6-position), then *Level*.
- Compass calibration, with the battery fitted and the GPS screwed into the nose.

## 3. Motors (props OFF)

- Motor order and spin direction follow ArduPilot's **Quad X** diagram for `Q_FRAME_TYPE = 1`, drawn in the hover attitude. Check each motor with *Motor Test* and swap the motor leads or `SERVOx_FUNCTION` until they match.
- Reverse a motor with the ESC tool (BLHeli_32 Suite / AM32 configurator via passthrough), not by rewiring the stack.

## 4. Radio (ExpressLRS)

- Flash the RX and TX with the same ELRS major version and binding phrase (ExpressLRS Configurator).
- RX wiring: RX-TX → **R6**, RX-RX → **T6**, 5 V, GND. `SERIAL6_PROTOCOL = 23` is already in the param file.
- Map modes to a 6-position switch: `QSTABILIZE`, `QHOVER`, `QLOITER`, `FBWA`, `QRTL`, plus a separate arm switch.

## 5. Video and OSD (HDZero)

- The VTX plugs into the FC's HD/VTX port (9 V + GND + UART). The param file assumes **UART1**. Check your board's silkscreen and move the `SERIAL1_*` lines if your connector is on another UART.
- `OSD_TYPE = 5`, `SERIALx_PROTOCOL = 42`, `OSD1_TXT_RES = 1` (HD). HDZero garbles text at resolution `2`.

## 6. First flights

1. Bench: props off, arm in `QSTABILIZE`, check every control input moves the right motors.
2. Tethered or low hover in `QSTABILIZE`, then run QuadPlane autotune (`QAUTOTUNE`) in hover.
3. `QLOITER` once GPS and the compass are healthy.
4. Only after a stable hover: transition at 30 m+ in `FBWA`, with a quick switch back to `QHOVER`.

5. **Going fast (target 200 km/h / 56 m/s):** fit the airspeed sensor and calibrate it before trusting it (`ARSPD_USE = 1` only after the HUD reads sensibly). Recompute `Q_TAILSIT_DSKLD` from your real all-up weight. Raise speed in steps (25 → 35 → 45 → 56 m/s). If it oscillates at speed, lower `Q_TAILSIT_GSCMIN`. Swap 7×5 props for 7×6 only once hover and transitions are solid.

Always follow your local aviation rules (registration, line-of-sight/FPV spotter rules, no-fly zones).

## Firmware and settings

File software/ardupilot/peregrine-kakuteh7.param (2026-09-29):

# Peregrine VTOL tail-sitter: ArduPlane starter parameters
# Target firmware: ArduPlane 4.5.x or newer, board "KakuteH7" (Holybro Kakute H7 v1.3+)
# Airframe: copter tail-sitter (4 motors, no control surfaces), 6S, 7" props (5-6" pitch)
# Design goal: 200 km/h (about 56 m/s) in forward flight
#
# !!! STARTER VALUES, NOT FLIGHT-TESTED !!!
# - Load with the PROPS OFF. Verify every motor's position and spin direction on the
#   Motor Test page before fitting props.
# - AHRS_ORIENTATION, accel calibration and level trim are done in the FIXED-WING attitude
#   (nose horizontal, canards level). See software/SETUP.md.
# - Tune in QSTABILIZE/QHOVER first, then QLOITER, then transitions at a safe altitude,
#   then raise speed in steps (25 -> 35 -> 45 -> 56 m/s) while watching for oscillation.
#
# Load order: set Q_ENABLE=1, write, REBOOT, refresh params, then load this whole file.

# ---------- QuadPlane / motor-only tail-sitter ----------
Q_ENABLE,1
Q_FRAME_CLASS,1
Q_FRAME_TYPE,1
# 2 = copter tail-sitter without control surfaces
Q_TAILSIT_ENABLE,2
# nose-down pitch (deg) at which the forward transition is complete
Q_TAILSIT_ANGLE,45

# ---------- Airspeed sensor (Matek ASPD-4525, MS4525DO on I2C) ----------
# Keep ARSPD_USE,0 until the sensor reads sensibly (blow on the pitot, check the HUD),
# then set it to 1. Check ARSPD_BUS against the I2C bus used on your board.
ARSPD_TYPE,1
ARSPD_USE,0
AIRSPEED_MIN,18
AIRSPEED_CRUISE,30
AIRSPEED_MAX,56

# ---------- High-speed gain scaling (tail-sitter) ----------
# Motor-only control gets far more sensitive as speed rises. Disk-theory scaling (bit 2)
# estimates the airflow over the props from thrust + airspeed and scales gains down.
# Q_TAILSIT_DSKLD = all-up mass (kg) / total prop disk area (m^2):
#   about 1.2 kg / (4 x pi x 0.0889^2 = 0.0993 m^2) = about 12. Recompute with your real weight.
Q_TAILSIT_GSCMSK,4
Q_TAILSIT_DSKLD,12
Q_TAILSIT_GSCMIN,0.3
Q_TAILSIT_GSCMAX,2

# ---------- Motors: Tekko32 4-in-1, DShot600, BLHeli_32 ----------
Q_M_PWM_TYPE,6
SERVO1_FUNCTION,33
SERVO2_FUNCTION,34
SERVO3_FUNCTION,35
SERVO4_FUNCTION,36
SERVO_BLH_AUTO,1
SERVO_DSHOT_ESC,1
Q_M_SPIN_ARM,0.08
Q_M_SPIN_MIN,0.12
# high-pitch props hover at a higher throttle than 7x4s
Q_M_THST_HOVER,0.35

# ---------- Serial ports (KakuteH7 hwdef) ----------
# SERIAL3 = UART3 -> Holybro Micro M10 GPS
SERIAL3_PROTOCOL,5
GPS_TYPE,2
# SERIAL6 = UART6 (R6/T6 pads) -> ExpressLRS receiver (CRSF)
SERIAL6_PROTOCOL,23
RSSI_TYPE,3
# SERIAL7 = UART7 (R7 pin on the ESC connector) -> ESC telemetry
SERIAL7_PROTOCOL,16
SERVO_BLH_TRATE,10
# SERIAL1 = UART1 (T1/R1) -> HDZero Freestyle V2 VTX, MSP DisplayPort OSD
# Check which UART your VTX connector uses on the silkscreen and move this block to match.
SERIAL1_PROTOCOL,42
SERIAL1_BAUD,115
OSD_TYPE,5
MSP_OPTIONS,0
OSD1_TXT_RES,1

# ---------- Battery (Tekko32 current sensor via the ESC connector) ----------
BATT_MONITOR,4
BATT_CAPACITY,2200
BATT_LOW_VOLT,21.0
BATT_CRT_VOLT,19.8

# ---------- Failsafes ----------
THR_FAILSAFE,1
FS_LONG_ACTN,1

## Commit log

2026-09-29 Initial release: Kārearea VTOL tail-sitter
    STEP files of all own parts + assembly (no vendor models), BOM with
    purchase links, wiring guide, ArduPlane tail-sitter parameters,
    renders and Flow Simulation results.
    [Arm.step, Avionics Tray.step, Battery CNHL 6S 2200mAh.step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]
2026-09-29 Design for 200 km/h: spars, props, airspeed sensor, CFD
    - CAD: 6 mm carbon spar channel in each wing panel, 2 mm carbon rod
    channel in each canard, battery pocket lengthened to 111 mm
    - BOM: 7x5 / 7x6 high-pitch props, carbon tube + rod, Matek
    ASPD-4525 airspeed sensor, ASA / PA-CF print advice
    - ArduPilot: airspeed sensor, AIRSPEED_MIN/CRUISE/MAX, tail-sitter
    disk-theory gain scaling (Q_TAILSIT_GSCMSK=4, DSKLD, GSCMIN/MAX)
    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
    [Arm.step, Avionics Tray.step, Body.step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]
2026-09-29 BOM: estimated NZD cost per part, subtotals and total cost
2026-09-30 Only claim what the repo contains
    - Remove carbon tube/rod from BOM and README (not needed; channels in
    the CAD are optional and empty); totals updated
    - Tray/body descriptions match the actual CAD features
    - Design credit wording; note renders vs photos, pitot mount pending
2026-09-30 Rev 2 three-piece fuselage for 250 mm printers; verified BOM links
    - Body Rev 2 (245 mm) + Nose Cone Rev 2 (extended, service hatch) +
    Tail Cap Rev 2, joined by flush twist-lock bayonets with snap bumps
    - Every BOM item: verified official/retailer page + AliExpress search
    link (individual AliExpress listings kept expiring)
    - Micro V2 camera discontinued -> Micro V3; HDZero BoxPro as the
    best-value goggle; prices and totals updated
    [Body Rev 2.step, Body.step, Nose Cone Rev 2.step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]
2026-09-30 Screw-off nose tip for camera access
    Nose Tip Rev 2 screws onto a threaded collar (2.5 mm pitch) on the
    nose bulkhead, so the camera can be fitted and its pivot/GPS screws
    reached. Fit-checked: zero interference across all Rev 2 parts.
    [Nose Cone Rev 2.step, Nose Tip Rev 2.step]
